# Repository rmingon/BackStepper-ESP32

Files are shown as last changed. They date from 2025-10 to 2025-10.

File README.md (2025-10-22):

# BackStepper-ESP32

BackStepper-ESP32 is a custom control board that bolts onto the rear face of a NEMA17 stepper motor and embeds an ESP32 for closed-loop or network-connected motion projects. The PCB combines power regulation, a DRV8825 microstepping driver, and a USB-C interface so a single board can power, drive, and program the motor controller without additional wiring harnesses.

> Designed with KiCad 9.0 (2025 snapshot); all project files live under `hardware/`.

## Visuals

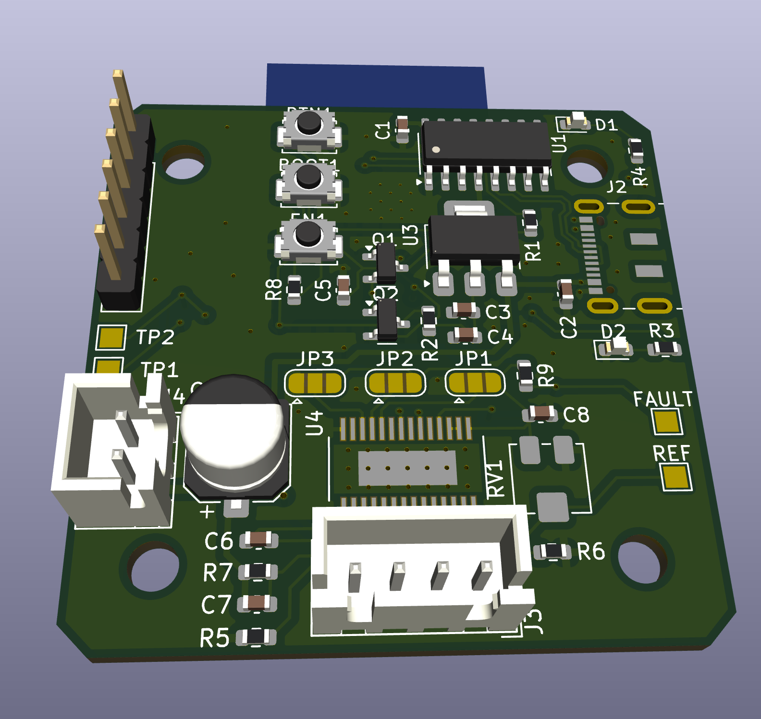
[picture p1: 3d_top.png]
3D top render of the BackStepper-ESP32 PCB


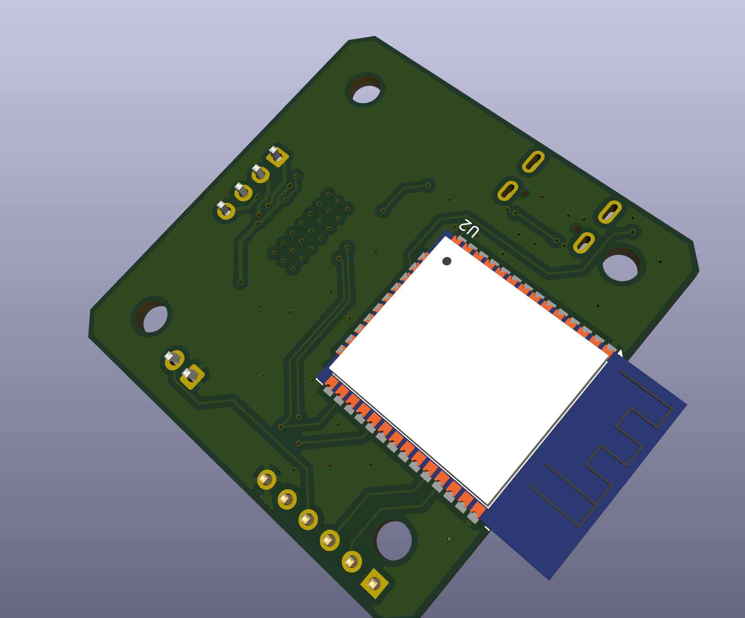
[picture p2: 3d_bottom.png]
3D bottom render showing the NEMA17 mounting face


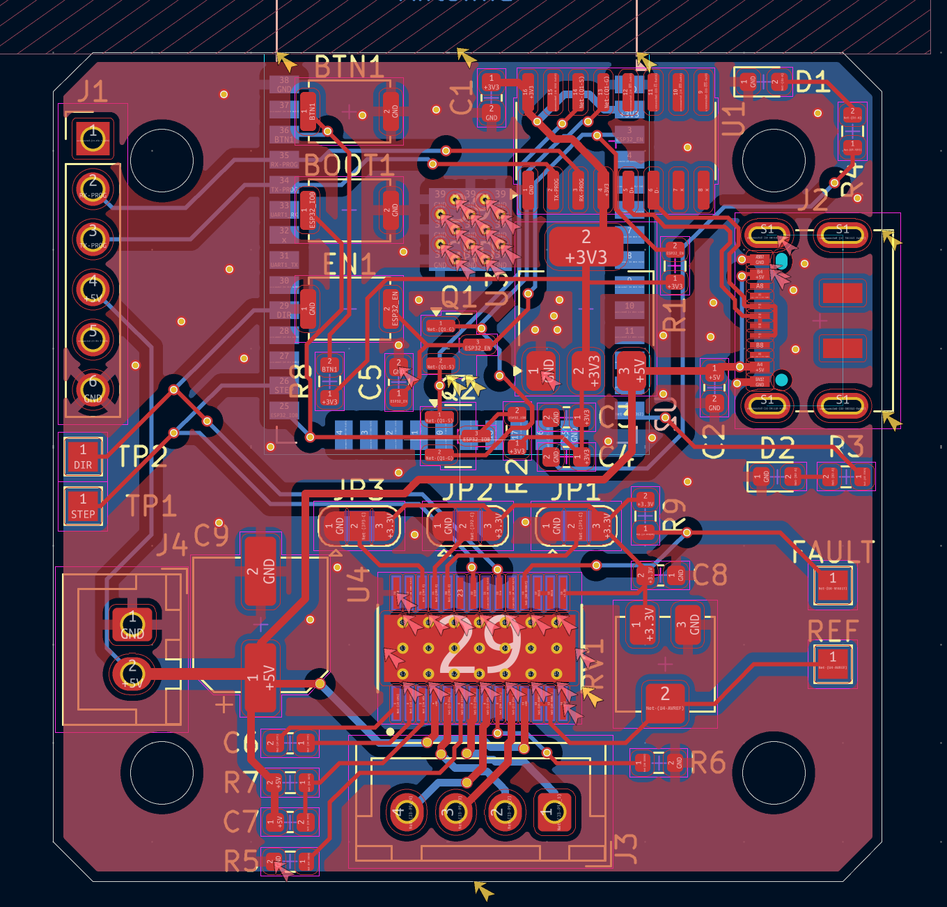
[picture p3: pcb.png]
Layer view of the assembled PCB layout


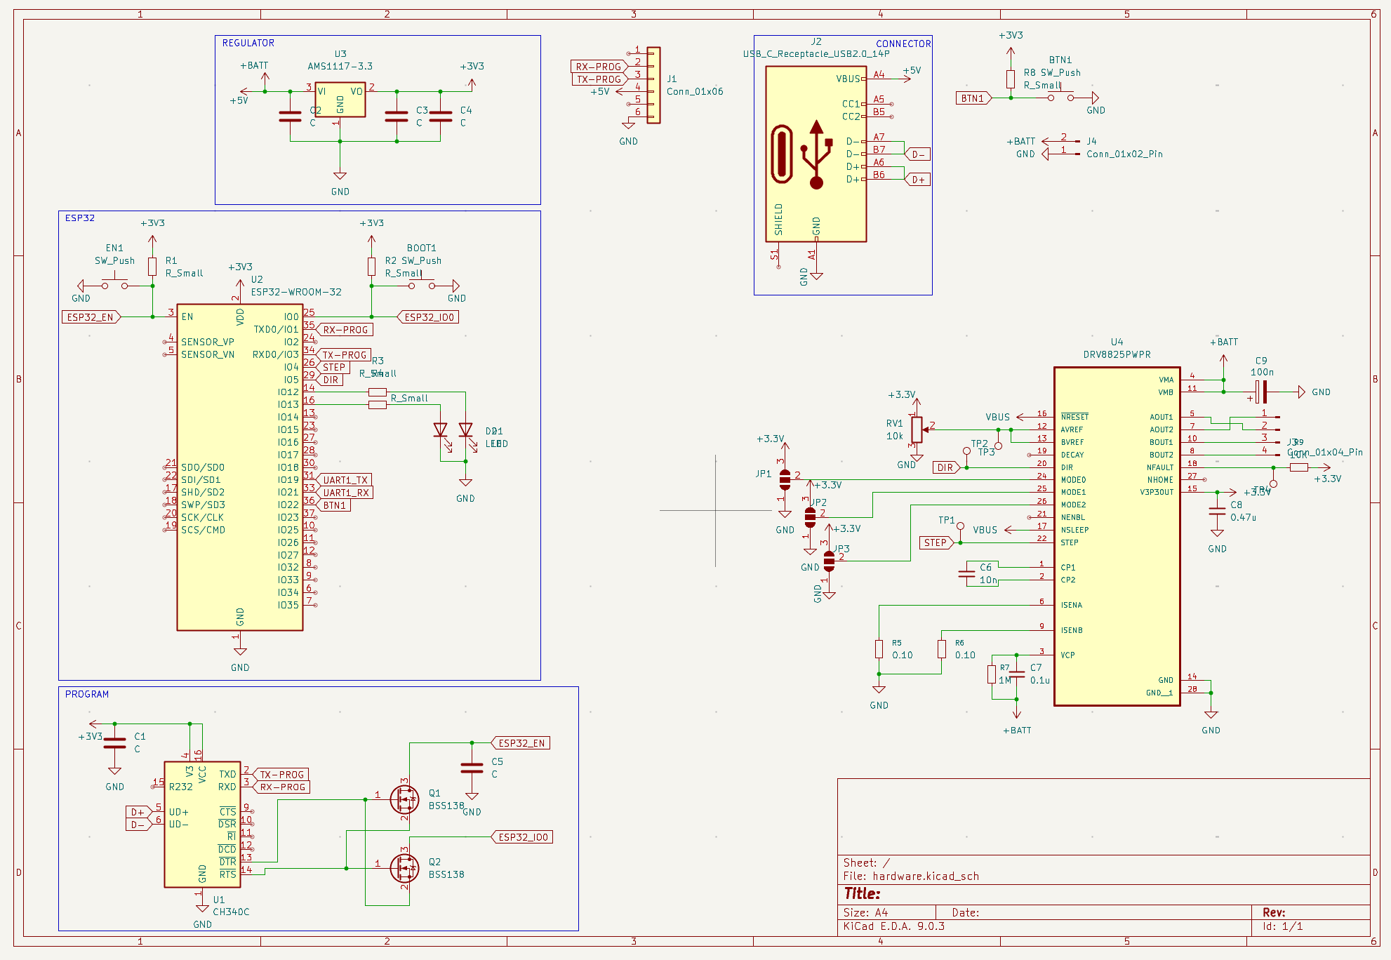
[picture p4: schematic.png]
High-level schematic overview


## Highlights

- ESP32-WROOM-32 module exposed for Wi-Fi/Bluetooth firmware as well as classic STEP/DIR motion control.
- DRV8825 stepper driver with 1/32 microstepping support and dedicated test pads on the STEP and DIR nets.
- CH340C USB-to-UART connected to a USB-C receptacle for flashing firmware and optionally powering the board.
- AMS1117-3.3 linear regulator fed from the +5 V plane to supply the ESP32 module and logic.
- JST-XH connectors for motor phases and the external 5 V feed, plus a 1×6 2.54 mm header for auxiliary serial access.
- Boot push-button on IO0 and CH340-controlled RTS/DTR FETs for hands-free flashing with `esptool.py`.
- Status LEDs on ESP32 IO12 and IO13 that can be repurposed for application feedback.
- Mounting hole pattern sized for the M3 boss spacing on a NEMA17 housing so the board can be screwed directly to the motor.

## Core Blocks

- **ESP32 module (`U2`)** – Provides dual-core MCU with Wi-Fi / BLE. STEP is on `IO4`, DIR on `IO5`, and UART0 is routed both to the CH340C and the breakout header.
- **Power regulation (`U3`)** – AMS1117-3.3 drops the shared +5 V plane down to 3.3 V for the ESP32 and CH340. Keep input below 6 V; logic and motor power are tied together on +5 V in this revision.
- **USB interface (`J2` + `U1`)** – USB-C receptacle wired for USB 2.0. CH340C handles the USB-to-UART bridge with RTS/DTR driving BSS138 FETs (`Q1`, `Q2`) to toggle EN and IO0 for automatic bootloader entry.
- **Stepper driver (`U4`)** – TI DRV8825 in HTSSOP package. Solder jumpers select the microstepping mode and sense resistor network sets coil current (see schematic for chosen values). Outputs route straight to the JST-XH motor connector.
- **User I/O** – `BTN1` pulls IO0 to ground for manual boot, status LEDs (`D1`, `D2`) sit on IO13 and IO12, and `TP1`/`TP2` break out STEP and DIR for probing or external drive injection.

## Connectors & Controls

| Ref  | Type / Pitch | Pinout (1 → n) | Notes |
|---|---|---|---|
| `J2` | USB-C (USB 2.0) | VBUS, D-, D+, CC1/CC2, shield | Powers CH340C/ESP32 from 5 V VBUS and provides the programming link. |
| `J4` | JST-XH 1×2 vertical | 1: GND · 2: +5 V | Primary power input. In this design +5 V feeds both DRV8825 VMOT and the AMS1117 regulator. |
| `J3` | JST-XH 1×4 vertical | 1: AOUT2 · 2: AOUT1 · 3: BOUT1 · 4: BOUT2 | Connect the stepper phases A/B (watch the order to match motor datasheet). |
| `J1` | 1×6 2.54 mm header | 1: NC · 2: RX0 · 3: TX0 · 4: +5 V · 5: NC · 6: GND | Aux UART header for programming/debug or external peripherals. |
| `BTN1` | Tactile push-button | IO0 ↔ GND | Forces the ESP32 boot pin low; use with EN toggle to enter download mode. |
| `TP1` | Test pad | STEP | Logic probe / scope pad tied to DRV8825 STEP and ESP32 IO4. |
| `TP2` | Test pad | DIR | Logic probe / scope pad tied to DRV8825 DIR and ESP32 IO5. |

## Microstepping Jumpers

Three solder jumpers strap DRV8825 `MODE0..2`. Each jumper has **GND** on the silkscreened dot side (pad A) and **3.3 V** on the opposite side (pad B). Leaving a jumper open lets the DRV8825’s internal pulldown pull the mode low.

| Microstep mode | `JP1` (MODE0) | `JP2` (MODE1) | `JP3` (MODE2) |
|---|---|---|---|
| Full step | open (low) | open (low) | open (low) |
| 1/2 step | short to 3.3 V| open | open |
| 1/4 step | open | short to 3.3 V| open |
| 1/8 step | short to 3.3 V| short to 3.3 V| open |
| 1/16 step | open | open | short to 3.3 V|
| 1/32 step | short to 3.3 V| open | short to 3.3 V|
| 1/32 step | open | short to 3.3 V| short to 3.3 V|
| 1/32 step | short to 3.3 V| short to 3.3 V| short to 3.3 V|

Reflow a small solder bridge between the center pad and the desired side to change the logic level. Remove bridges with solder wick when changing configuration.

## Powering and Using the Board

1. **Supply** – Feed +5 V either through the USB-C port (VBUS) or the `J4` JST connector. Because the DRV8825 VM pins are tied to +5 V, this revision targets low-voltage steppers; do not exceed 5–6 V on the supply without redesigning the power stage.
2. **Motor hookup** – Wire the stepper to `J3`. If the motor runs rough, swap pins within a phase pair to keep coil polarity consistent.
3. **Programming** – Connect USB-C to your PC. The CH340C enumerates as a serial port. `esptool.py` can reset the ESP32 automatically via RTS/DTR. Use `BTN1` only if manual boot selection is needed.
4. **Firmware** – STEP/DIR live on IO4/IO5; UART1 (IO19/IO21) is broken out internally if you need another serial channel. LEDs on IO12/IO13 provide quick visual feedback.

Current sense resistors and VREF test points are accessible near the driver; tune current following the DRV8825 datasheet.

## Repository Layout

- `hardware/` – KiCad project (`.pro`, `.sch`, `.kicad_pcb`) plus backup caches.
- `Capture d’écran *.png` – Draft renders / screenshots of the PCB as designed in the IDE.

Generate manufacturing outputs from KiCad (`File → Fabrication Outputs`) against the `hardware.kicad_pro` project once component values are finalised.

## License

This project is released under the **CERN Open Hardware Licence v2 Strongly Reciprocal (CERN-OHL-S-2.0)**. See the `LICENSE` file for the full text and your obligations when modifying or distributing the design or fabricated hardware.

## Next Steps

- Add a dedicated EN/RESET push-button if manual resets become necessary.
- Consider isolating motor and logic rails or moving to a higher-voltage supply for more torque.
- Document tested firmware builds and pin assignments once the mechanical integration is validated.

Feel free to open issues or PRs as the design evolves. Happy hacking!

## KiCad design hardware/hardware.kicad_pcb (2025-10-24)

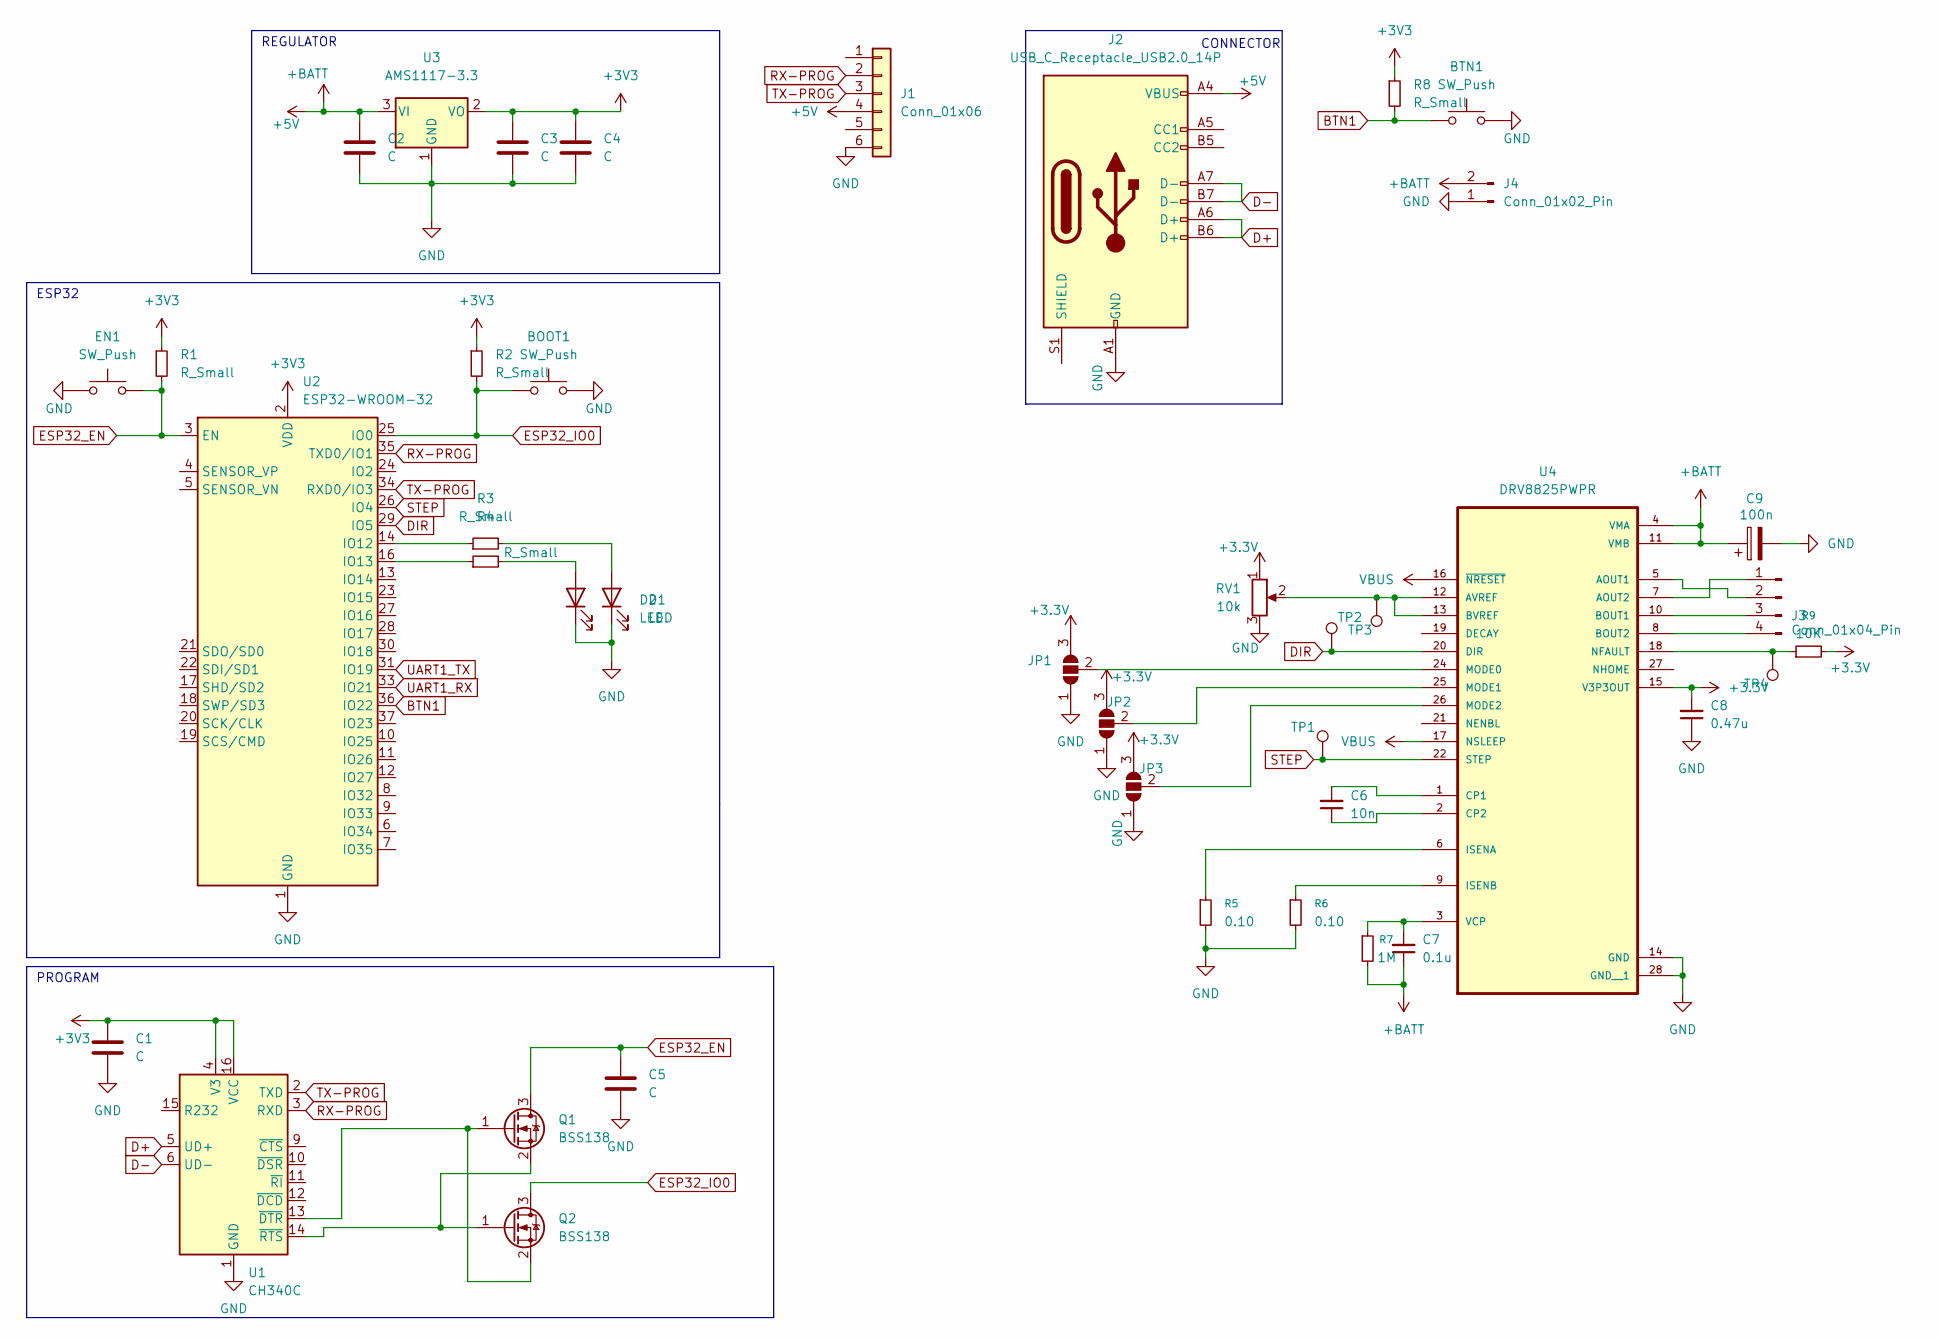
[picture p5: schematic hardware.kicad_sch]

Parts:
BOOT1: SW_Push; SW_Push_SPST_NO_Alps_SKRK; LCSC C398053
BTN1: SW_Push; SW_Push_SPST_NO_Alps_SKRK; LCSC C398053
C1, C2, C4: C; C_0603_1608Metric; LCSC C30926
C3, C5: C; C_0603_1608Metric; LCSC C19702
C6: 10n; C_0603_1608Metric
C7: 0.1u; C_0603_1608Metric
C8: 0.47u; C_0603_1608Metric
C9: 100n; CP_Elec_6.3x5.7
D1: LED; LED_0603_1608Metric; LCSC C19171301
D2: LED; LED_0603_1608Metric; LCSC C434425
EN1: SW_Push; SW_Push_SPST_NO_Alps_SKRK; LCSC C398053
J1: Conn_01x06; PinHeader_1x06_P2.54mm_Vertical
J2: USB_C_Receptacle_USB2.0_14P; USB_C_Receptacle_JAE_DX07S016JA1R1500; LCSC C963213
J3: Conn_01x04_Pin; JST_XH_B4B-XH-A_1x04_P2.50mm_Vertical
J4: Conn_01x02_Pin; JST_XH_B2B-XH-A_1x02_P2.50mm_Vertical
JP1, JP2, JP3: SolderJumper_3_Open; SolderJumper-3_P1.3mm_Open_RoundedPad1.0x1.5mm
Q1, Q2: BSS138; SOT-23; LCSC C7420338
R1, R2, R8: R_Small; R_0603_1608Metric; LCSC C98220
R3, R4: R_Small; R_0603_1608Metric; LCSC C2906975
R5, R6: 0.10; R_0603_1608Metric
R7: 1M; R_0603_1608Metric
R9: 10K; R_0603_1608Metric
RV1: 10k; Potentiometer_Bourns_3214J_Horizontal
TP1, TP2, TP3, TP4: TestPoint; TestPoint_Pad_1.5x1.5mm
U1: CH340C; SOIC-16_3.9x9.9mm_P1.27mm; LCSC C84681
U2: ESP32-WROOM-32; LCSC C82899
U3: AMS1117-3.3; SOT-223-3_TabPin2; LCSC C6186
U4: DRV8825PWPR; IC_TPS61196PWPRQ1

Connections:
+3.3V: C8.2, JP1.3 (B), JP2.3 (B), JP3.3 (B), R9.2, RV1.1, U4.15 (V3P3OUT)
+3V3: C1.1, C3.1, C4.1, R1.1, R2.1, R8.1, U1.4 (V3), U1.16 (VCC), U2.2 (VDD), U3.2 (VO)
+5V: C2.1, C7.1, C9.1, J1.4, J2.A4 (VBUS), J2.A9 (VBUS), J2.B4 (VBUS), J2.B9 (VBUS), J4.2, R7.2, U3.3 (VI), U4.4 (VMA), U4.11 (VMB)
BTN1: BTN1.1, R8.2, U2.36 (IO22)
D+: J2.A6 (D+), J2.B6 (D+), U1.5 (UD+)
D-: J2.A7 (D-), J2.B7 (D-), U1.6 (UD-)
DIR: TP2.1, U2.29 (IO5), U4.20 (DIR)
ESP32_EN: C5.1, EN1.2, Q1.3 (D), R1.2, U2.3 (EN)
ESP32_IO0: BOOT1.1, Q2.3 (D), R2.2, U2.25 (IO0)
GND: BOOT1.2, BTN1.2, C1.2, C2.2, C3.2, C4.2, C5.2, C8.1, C9.2, D1.1 (K), D2.1 (K), EN1.1, J1.6, J2.A1 (GND), J2.A12 (GND), J2.B1 (GND), J2.B12 (GND), J4.1, JP1.1 (A), JP2.1 (A), JP3.1 (A), R5.2, R6.2, RV1.3, U1.1 (GND), U2.1 (GND), U2.15 (GND), U2.38 (GND), U2.39 (GND), U3.1 (GND), U4.14 (GND), U4.28 (GND__1)
unnamed: D1.2 (A), R4.2
unnamed: D2.2 (A), R3.2
unnamed: J3.1, U4.7 (AOUT2)
unnamed: J3.2, U4.5 (AOUT1)
unnamed: J3.3, U4.10 (BOUT1)
unnamed: J3.4, U4.8 (BOUT2)
unnamed: JP1.2 (C), U4.24 (MODE0)
unnamed: JP2.2 (C), U4.25 (MODE1)
unnamed: JP3.2 (C), U4.26 (MODE2)
unnamed: Q1.1 (G), Q2.2 (S), U1.13 (~DTR)
unnamed: Q1.2 (S), Q2.1 (G), U1.14 (~RTS)
unnamed: R3.1, U2.14 (IO12)
unnamed: R4.1, U2.16 (IO13)
unnamed 23: RV1.2, TP3.1, U4.12 (AVREF), U4.13 (BVREF); also elsewhere on the board
unnamed: C6.2, U4.1 (CP1)
unnamed: C6.1, U4.2 (CP2)
unnamed: R5.1, U4.6 (ISENA)
unnamed: R6.1, U4.9 (ISENB)
unnamed 28: R9.1, TP4.1, U4.18 (NFAULT); also elsewhere on the board
unnamed: C7.2, R7.1, U4.3 (VCP)
RX-PROG: J1.2, U1.3 (RXD), U2.35 (TXD0/IO1)
STEP: TP1.1, U2.26 (IO4), U4.22 (STEP)
TX-PROG: J1.3, U1.2 (TXD), U2.34 (RXD0/IO3)
UART1_RX: U2.33 (IO21)
UART1_TX: U2.31 (IO19)
VBUS: U4.16 (~NRESET), U4.17 (NSLEEP)

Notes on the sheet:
REGULATOR
ESP32
PROGRAM
CONNECTOR

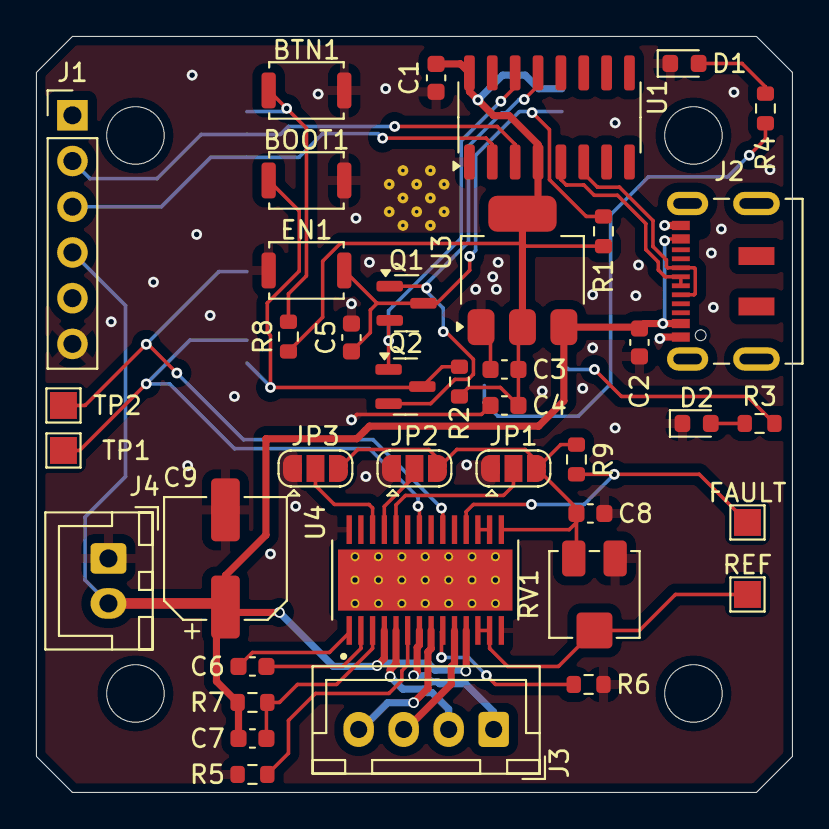
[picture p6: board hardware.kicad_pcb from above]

Board: 2 copper layers, 42.0 x 42.0 mm, 41 parts (1 on the bottom side), 34 nets.

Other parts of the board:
FAULT: TestPoint; TestPoint_Pad_1.5x1.5mm
REF: TestPoint; TestPoint_Pad_1.5x1.5mm

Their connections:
unnamed 23: REF.1; also elsewhere on the board
unnamed 28: FAULT.1; also elsewhere on the board

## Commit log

2025-10-22 add schematic
    [hardware.kicad_sch]
2025-10-22 add pcb size for nema17
    [hardware.kicad_pcb]
2025-10-22 finish pcb wiring
    [hardware.kicad_pcb, hardware.kicad_sch]
2025-10-24 gnd capacitor pcb wiring
    [hardware.kicad_pcb]
